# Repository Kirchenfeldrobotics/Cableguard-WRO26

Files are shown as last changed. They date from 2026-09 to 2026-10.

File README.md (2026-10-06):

# Cableguard

**Guarding the lifelines of the Alps.** An autonomous robot that inspects steel wire ropes.

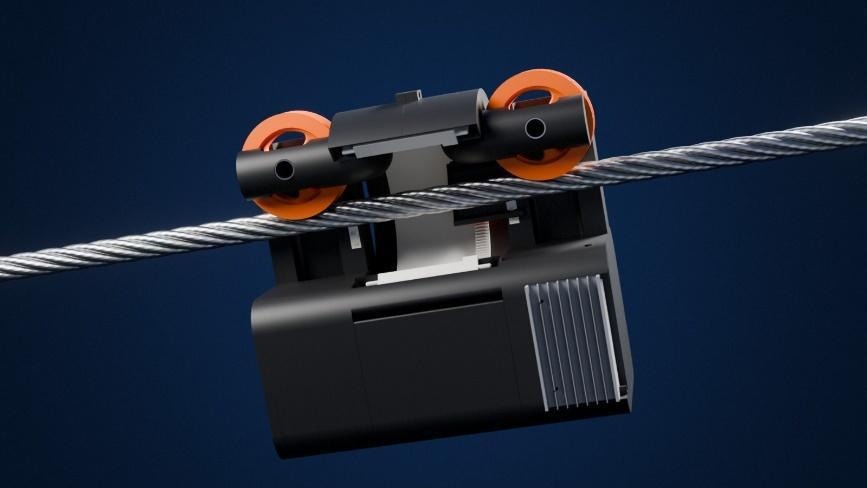
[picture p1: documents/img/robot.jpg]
Cableguard on a rope


**Figure 1.** Cableguard on a rope, rendered from our CAD model.

The operator places Cableguard on the rope and presses start, and the robot works alone. Two
cameras on a rotating ring photograph all four sides of the rope, a YOLO26 network that we
trained on about 22,000 rope images marks eight classes of damage, and the steps of the motor
give the position of every photo. A web app shows the inspection live and compares it with
earlier ones.

We are Kirchenfeldrobotics, a student robotics club from Bern, and we built Cableguard for the
World Robot Olympiad 2026 (Future Innovators, Senior). This README describes how the robot is
built, how its software works and how to run it. The whole story is in our
[project report](documents/CableGuard_Report%20_Kirchenfeldrobotics.pdf), and the
[movie](documents/CableGuard_Movie_Kirchenfeldrobotics.mp4) shows the robot.

## The problem

A steel rope does not fail suddenly. Wires break, corrosion and lightning leave marks, and the
rope weakens over years. On 23 May 2021 the haul rope of the Stresa–Mottarone cable car in
Italy snapped and fourteen people died. Court experts later found that 68 % of the wires at the
break had failed from fatigue and corrosion long before that day.

Switzerland has about 2,450 cableways, and every second small cableway has financial problems.
Today a person checks a rope by riding on a slow-moving gondola, which is slow, expensive and
prone to error. A magnetic test by a testing body happens only every few years. Cableguard
works in the gap between two tests. It photographs the whole rope as often as the operator
wants, and damage that grows slowly shows up as a change between two runs.

Cableguard sees the surface of the rope. It adds to the magnetic test by an accredited body and
never replaces it.

## The robot in numbers

| Property | Value |
| --- | --- |
| Size of the casing | 277 x 160 x 245 mm |
| Weight | 3 kg |
| Test rope | Steel rope, 22 mm diameter, 1.6 m long |
| Scan speed | About 3 cm per second, about 110 m per hour |
| Power | 3S LiPo battery, 11.1 V nominal |
| Computer | Raspberry Pi 5 |
| Motors | 2 x NEMA 23 stepper motor, each with a TB6600 driver |
| Cameras | 2 x Raspberry Pi Camera Module 3 Wide with LED light |
| Network | YOLO26s, 9.5 million parameters, eight classes of damage |
| Parts of one robot | About CHF 400 |

## Mechanics

The body of the robot hangs below the rope. Two wheels on top carry it, and the rope passes
through the upper part of the casing, where a ring with the two cameras surrounds it (Figure 2).

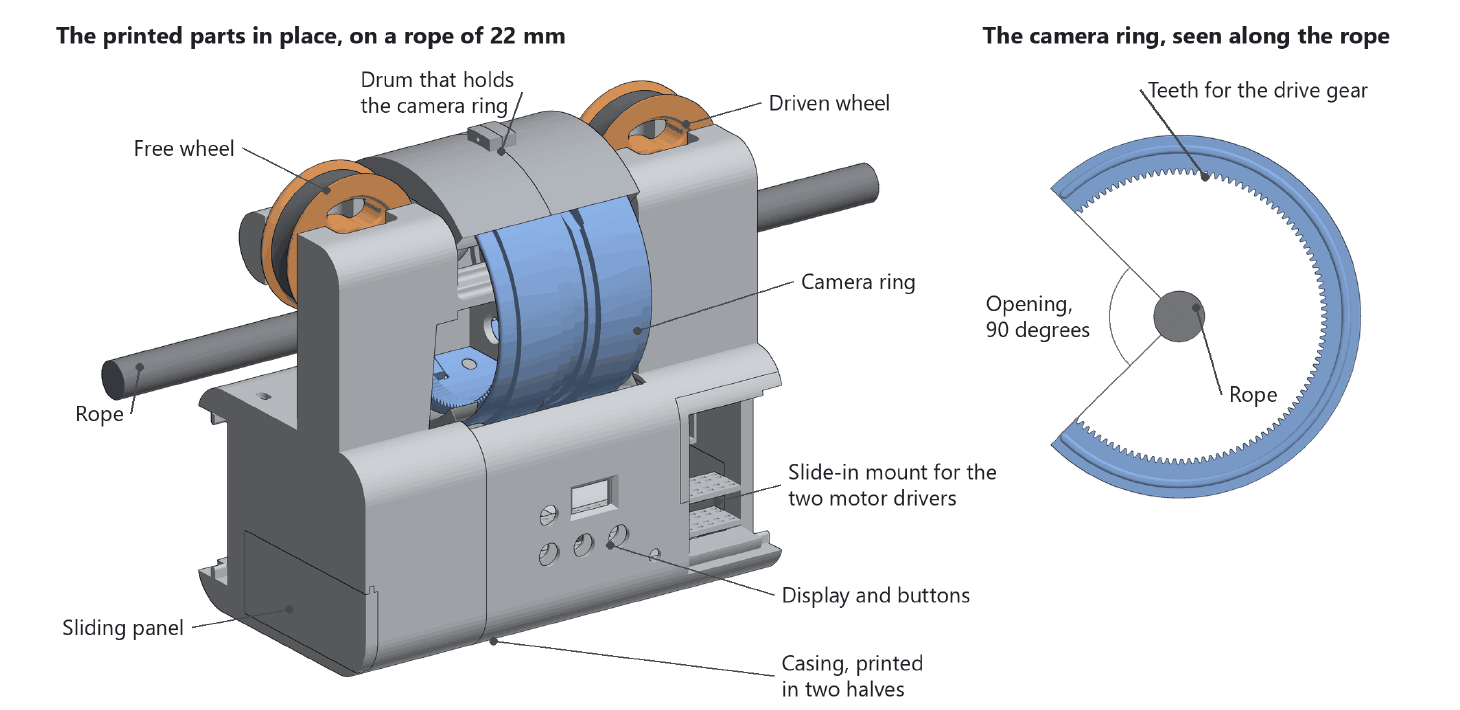
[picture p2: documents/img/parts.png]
The printed parts and the camera ring


**Figure 2.** The printed parts of the robot and the camera ring, drawn from our CAD model.
Motors, belt, cameras and electronics are not shown.

### Drive

The robot rides on two wheels. A NEMA 23 stepper motor drives one of them through a GT2 belt
with a printed tensioner, and the second wheel runs free. The first wheels were printed from PLA
and slipped on the steel. The current wheels have an insert of flexible TPU with a V-shaped
groove. The weight of the robot presses the rope into the V, and this wedge gives the grip that
a flat wheel does not have.

We chose a stepper motor because it moves in fixed steps, 200 per turn, each split into 8
microsteps by the driver. The robot counts every microstep it sends, so it knows its position
without an extra sensor. The weakness of counting steps is slip: if the wheel slips, the robot
believes it is further along the rope than it is. We have not measured slip yet.

### Why a camera ring

A rope is round, and one camera sees less than half of it. The testing institutes therefore
mount four cameras around the rope. We wanted the same coverage with fewer parts. The Raspberry
Pi 5 has two camera connectors, and every further camera adds a cable, weight and a picture for
the network to process. So two cameras sit opposite each other on a ring, and a second NEMA 23
turns the ring through a printed gear.

The ring has an opening of 90 degrees. To put the robot on a rope, the ring turns to its open
position, the rope slips through the opening into the centre of the ring and the wheels come to
rest on the rope. Two rules follow from the hardware. The ring always swings back the way it
came, because the cameras hang on their cables and a ring that kept turning would wind them up.
And since the ring has no end switch, whoever sets up the robot leaves it at its parking angle
and the software counts every step from there.

### Casing and material

Every structural part is 3D printed in PLA: both halves of the casing, the drum that holds the
camera ring, the wheel hubs and all mounts, 16 pieces in total. Only the axles, spacers, screws
and belts are bought parts. We print because we can redesign a part ourselves and test it a day
later, without a workshop.

The casing is a prototype. It encloses the electronics, but it has no seals, and we have not
tested it in rain or frost yet. The files to print are in [`3d-model/print/stl`](3d-model/print/stl),
the CAD files in [`3d-model/cad/step`](3d-model/cad/step) and the list of all parts in
[`3d-model/BOM.md`](3d-model/BOM.md).

## Electronics

One Raspberry Pi 5 runs everything on the robot: both motors, both cameras, the neural network
and the connection to the server.

| Component | Part | Connected to |
| --- | --- | --- |
| Computer | Raspberry Pi 5 | |
| Drive motor | NEMA 23 stepper motor with TB6600 driver | Step GPIO 18 (pin 12), direction GPIO 23 (pin 16) |
| Ring motor | NEMA 23 stepper motor with TB6600 driver | Step GPIO 12 (pin 32), direction GPIO 16 (pin 36) |
| Cameras | 2 x Raspberry Pi Camera Module 3 Wide with LED light | Both camera ports of the Pi |
| Distance sensor | TOF200C (VL53L0X laser sensor) | I2C bus 1, SDA on pin 3, SCL on pin 5 |
| Display | 0.96 inch OLED (SSD1306), 128 x 64 pixels | I2C bus 1, address 0x3C |
| Buttons | Red start button, white stop button. A third button is wired and has no function yet | GPIO 5 (pin 29) and GPIO 6 (pin 31), each switched to ground |
| Buzzer | | GPIO 26 (pin 37) |
| Mobile link | LTE module with SIM card | |
| Power | 3S LiPo battery (11.1 V nominal) and step-down converter | Battery voltage directly to the motor drivers, 5 V from the converter to the Pi |

Three decisions shaped the wiring.

**One computer.** A neural network needs a real processor, and the Pi 5 has the two camera
ports and the GPIO pins we need. A photo, the motor position at that moment and the result of
the network now live in one program, and nothing has to be synchronised over a cable.

**Usable without a phone.** Two buttons, a buzzer and a small display are enough to start a
run, stop it and see what the robot is doing. A button sends the same command as the web app,
so both always do the same thing. Each state has its own sound, and the display shows connection,
position and speed. The Pi pulls both button pins high from the moment it boots, so a button
held down during start-up cannot start the motor.

**Cables that explain themselves.** Three voltage levels, 12 V, 5 V and 3.3 V, meet in a small
space. Every cable carries a three-digit label with two digits for the component and one for
the pin. 013 is pin 3 of the drive motor driver, its step input.
[`documents/cable_label.md`](documents/cable_label.md) lists the labels and
[`documents/pins.md`](documents/pins.md) maps every label to a pin of the Pi.

## Software

The software runs on three devices. The robot inspects on its own, the server stores every
finding and the web app is the window for the operator (Figure 3). We wrote in Python,
TypeScript and C. Everything else we use is open source: FastAPI, Next.js, Ultralytics YOLO,
NCNN and the Raspberry Pi libraries for the cameras and the PIO block.

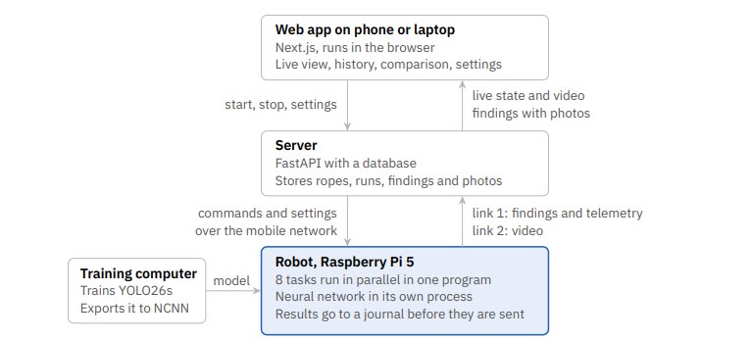
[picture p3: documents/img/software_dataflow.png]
Software architecture: three devices and two links from the robot to the server.


**Figure 3.** Software architecture: three devices and two links from the robot to the server.

### One scan cycle

1. Both cameras take a photo while the ring stands still.
2. The ring swings 90 degrees. During the swing the network analyses the two photos.
3. Both cameras take a second photo of the two sides that were hidden.
4. The ring swings back and the network analyses the second pair.
5. Every result is written to a journal with the position of the robot at the moment of the
   photo.

Only the shutter needs a ring that stands still. The network can work while the cameras move,
so turning and analysing happen at the same time (Figure 4).

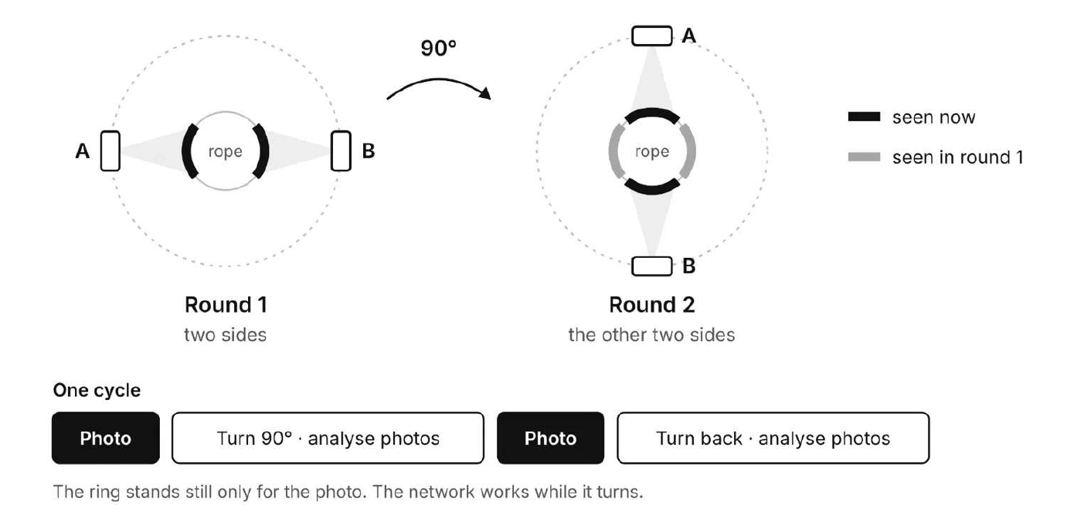
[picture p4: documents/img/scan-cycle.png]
Scan cycle of the camera ring


**Figure 4.** Scan cycle of the camera ring: two rounds of photos and one quarter turn.

Each camera delivers two pictures at once, 640 x 640 pixels for the network and 640 x 480 for
the live view. The scan cycle is one of nine tasks that run in parallel in one program
([`robot/src/app/main.py`](robot/src/app/main.py)).

| Task | What it does |
| --- | --- |
| Control link | Holds the connection for commands and results, sends the journal and a heartbeat every 5 seconds |
| Video link | Sends the newest picture of each camera |
| Frame stream | Takes the small picture of both cameras for the live view |
| Detection | The scan cycle: photos, quarter turns, network, reports |
| Guard | Stops the drive when the connection is lost while driving |
| Telemetry | Reports speed, position and state twice a second |
| Distance | Reads the distance sensor and watches for a rope socket |
| Display | Redraws the display |
| Update | Runs the update script when the operator asks for it |

### The robot sets its own speed

In the first weeks the operator chose the speed in the web app. A robot that drives faster than
its network can analyse leaves stripes of rope that nobody looks at, so now the robot measures
itself. At every start it runs nine test cycles and times the cameras and the network
separately. One photo covers a length *L* of rope, and the robot may travel exactly *L* per
cycle.

| What the robot calculates | Formula |
| --- | --- |
| Time for one quarter turn | `t_turn = max(H · D / R, t_ring)` |
| Time for one cycle | `T = R · (C / R + t_turn)` |
| Driving speed | `v = L / T` |

*C* is the camera time and *D* the network time of one cycle, *R* = 2 the number of photo
rounds and `t_ring` the fastest quarter turn of the ring. *H* = 1.5 is a safety factor, because
the network needs longer for a photo with damage than for the clean rope it was timed on. An
example: with *L* = 60 mm, *C* = 0.14 s and *D* = 1.2 s, which is 0.3 s per photo, the cycle
takes *T* = 1.94 s and the robot drives 31 mm per second, about 110 m per hour. The operator
only chooses start, stop and the direction.

The network sets the pace, and two parts can limit it. If the ring cannot swing a quarter turn
in the time the network needs, it takes the time it needs and the whole cycle grows around it.
And the speed stays inside the limits of the drive: a drive that cannot go slowly enough leaves
a gap between two photos, and the robot writes a warning to its log. The code is in
[`robot/src/vision/pacing.py`](robot/src/vision/pacing.py).

### Knowing the position

A finding is only useful with its position, and the position is the count of motor steps. Every
pulse has to arrive on time, also while the processor is busy with the network. Our first driver
made the pulses in Python, and the motor stuttered whenever the network ran.

The Raspberry Pi 5 contains a hardware block called PIO, four small state machines that run
independently of the processor. We wrote a program of seven instructions for it and a small C
library around it. The software hands the hardware a block of pulses, and the hardware plays it
with a resolution of one microsecond. The robot adds a block to its position only after the
hardware reports it as played, so the count cannot run ahead of the motor.

```
.side_set 1 opt
.wrap_target
    pull block      side 0       ; wait for a block, STEP stays low
    out x, 16                    ; x = steps - 1, OSR keeps the low-time count
step:
    mov y, osr      side 1 [7]   ; STEP high for 10 cycles
    nop                    [1]
low:
    jmp y-- low     side 0       ; STEP low for y + 1 cycles
    jmp x-- step
    push noblock                 ; block done
.wrap
```

The complete program of the PIO block for one stepper motor, from
[`robot/src/motion/stepgen.c`](robot/src/motion/stepgen.c).

Both motors use the same program, one state machine each. A block is one word: the number of
steps and the pause between them. While the robot drives, a thread feeds the hardware blocks of
20 milliseconds and keeps three of them queued. That is enough for a moment in which the
processor is busy, and few enough that a stop command does not wait behind a long queue.

### The neural network

We use YOLO26s, an object detector with 9.5 million parameters that was released in January
2026 for small computers without a graphics card. It draws a box around every damage and gives
a score of how sure it is.

For training we merged two public collections of rope photos with a script that unifies their
class lists. The merged set has about 22,000 images with 37,513 marked damages in eight classes.
We trained for 150 rounds on a graphics card and converted the result to NCNN, a format that
runs fast on the ARM processor of the Pi. On the validation photos, which were not used for
training, the network finds 96 % of all marked damages, and 74 % of its boxes are real damages.

| Class | AP50 | Marked damages in the data | Reported as |
| --- | --- | --- | --- |
| `wear` | 0.95 | 11,547 | Loss of metallic area |
| `kink` | 0.92 | 346 | Local fault |
| `bird_caging` | 0.87 | 488 | Local fault |
| `unknown_defect` | 0.72 | 580 | Local fault |
| `broken_wire` | 0.69 | 10,054 | Local fault |
| `mechanical_damage` | 0.55 | 3,326 | Local fault |
| `thunderbolt` | 0.48 | 4,025 | Local fault |
| `break` | 0.28 | 7,147 | Local fault |

Average precision per damage class at IoU 0.5 on the validation set, first training run on 13
September 2026. The mean is 0.68.

Two decisions follow from these numbers. The robot reports a box as soon as the network is 10 %
sure. A false alarm costs the operator one look at a photo, and a missed broken wire can cost
much more. And it reports each damage in the two groups that rope inspectors know, local fault
(LF) and loss of metallic area (LMA). The table shows why that helps. The network confuses
`break` with `broken_wire` and `thunderbolt` with `mechanical_damage`, because the two photo
collections use different names for the same damage. All four are local faults, so the report of
the robot stays correct.

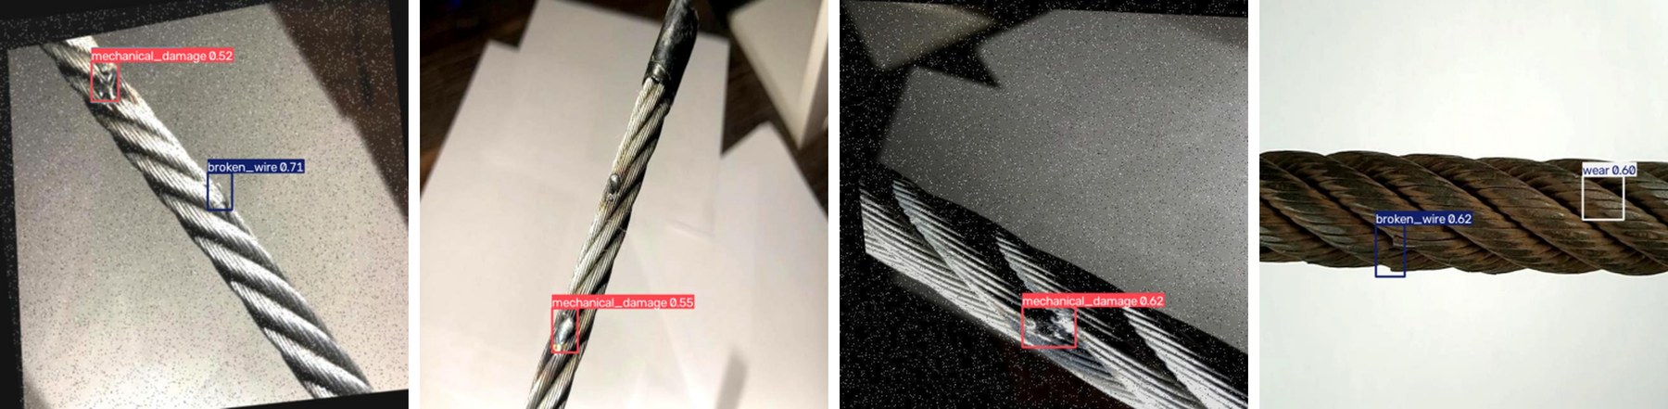
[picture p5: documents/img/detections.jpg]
Detections of our network


**Figure 5.** Four photos from the public test set with the boxes and confidence values of our
network.

The network runs as a separate program. NCNN holds the lock of the Python interpreter for a
whole analysis, so before that change every analysis froze the whole robot for a few hundred
milliseconds, including the thread that feeds the motor
([`robot/src/vision/detector.py`](robot/src/vision/detector.py)).

These numbers come from photos of other people's ropes. On our own test rope the detection
works well in our runs, but we have not yet counted hits and misses on prepared damage.

### Passing a rope socket

A rope ends in a thick metal fitting, the rope socket, and the camera ring cannot turn past it.
A laser distance sensor looks ahead. While the robot still stands it averages ten readings to
learn what the sensor normally sees. When something appears 10 cm nearer than that, the ring
parks at the one angle that leaves room for the socket and the network pauses. 50 cm after the
last sighting the ring closes and the scan continues. A tower is passed the same way.

The sensor compares with its own calibration and not with a fixed distance, because where the
beam lands depends on how the sensor sits and which rope it is. Two things can open the robot.
An opening by the sensor ends once the robot has driven clear. An opening the operator asked
for in the web app ends only when the operator closes it.

### Two links to the server

The robot keeps two connections to the server, one for commands and results and one for video,
so a video frame cannot delay a stop command. Both are WebSockets, and the robot signs in with
a token.

Every result is written to a journal on the memory card before it is sent, and after a
connection loss the robot continues at the byte where it stopped. If the connection breaks
while the robot drives, it stops and sounds the fault signal, because nobody could stop it
remotely.

Robot and server read their messages from the same file,
[`shared/comm_protocols/messages.py`](shared/comm_protocols/messages.py), so both sides always
speak the same protocol.

| Message | Direction | What it carries |
| --- | --- | --- |
| `alive` | Robot to server | Heartbeat every 5 seconds |
| `motion_telemetry` | Robot to server | Speed and position in microsteps and in metres, the scan speed the robot chose, whether it is open, the versions of the settings and of the software it runs on |
| `distance_telemetry` | Robot to server | Reading of the distance sensor |
| `vision_telemetry` | Robot to server | One per photo: boxes, class and confidence, position, and the photo itself if something was found |
| `defect` | Robot to server | A finding from a second sensor, kept for the magnetic head |
| `start`, `stop` | Server to robot | Drive in a direction, stop |
| `reset_origin` | Server to robot | Count the position from here, sent when a run is selected |
| `open`, `close`, `socket_watch` | Server to robot | Open or close the ring, arm the distance sensor |
| `settings` | Server to robot | The whole set of settings with a version number |
| `update` | Server to robot | Run the update script |

Telemetry is sent live, because a reading is worth nothing a second later. Photos with findings
go through the journal, because a detection that is not stored is a damage lost. Neither side
confirms a command. The robot reports its state in the telemetry, and the web app shows a
command as carried out only when the telemetry says so.

### Server and web app

The server is a FastAPI program with a database, SQLite by default. It stores ropes, runs,
findings and the photo every finding was made in. A finding belongs to a run, so the server
drops findings while no run is selected. When the operator selects a run, the server tells the
robot to count its position from zero.

The web app shows both camera streams, position and speed live, keeps every inspection of a
rope and compares two of them. One damage is usually photographed several times, so the web app
groups detections of the same type that are less than 0.5 m apart into one finding. In a
comparison, findings less than 1.5 m apart count as the same damage, so the operator sees what
is new and what has disappeared. Every run can be exported as a PDF. Operators log in with a
password or by holding their phone to an NFC tag on the robot.

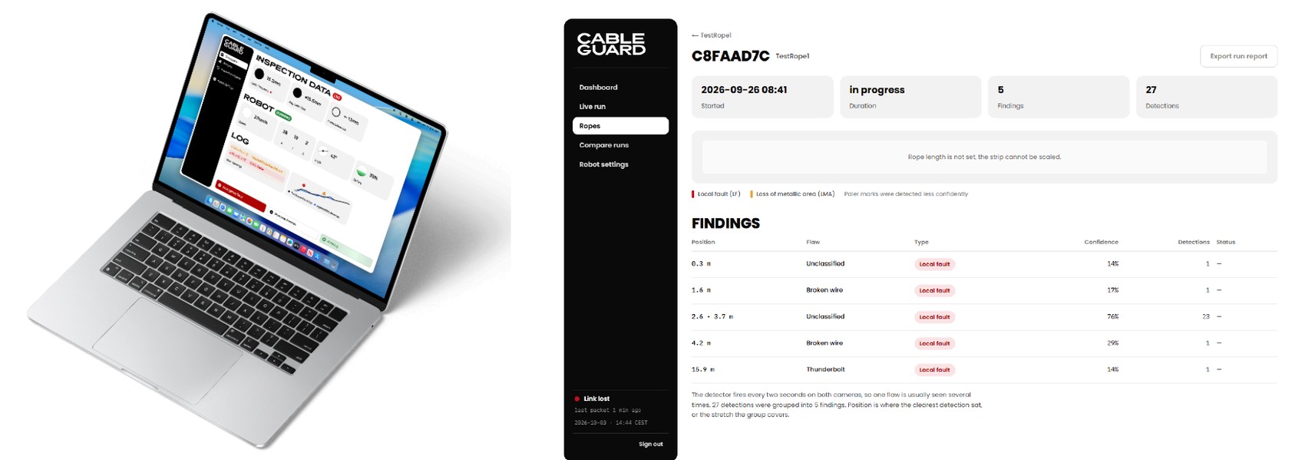
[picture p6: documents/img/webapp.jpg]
The web app


**Figure 6.** The web app: the dashboard on a laptop and the findings of one run with position,
flaw and confidence.

**Settings.** The robot has 31 settings in seven groups, from the microstepping of the drive to
the exposure of the cameras. They are defined once, in
[`shared/comm_protocols/settings.py`](shared/comm_protocols/settings.py), with their limits and
their explanation. The server stores the values of the operator, and the settings page draws
itself from that list, so a new setting is added in one place. The robot boots on its own
defaults and runs without a server.

**Update.** The settings page can also update the robot. The robot then runs the update script
that sits beside the repository on the Pi, which pulls the latest software and restarts the
program. The page shows the commit the robot runs on, so the operator sees that the update
worked ([`robot/src/app/update.py`](robot/src/app/update.py)).

The web app has its own [README](webapp/README.md) with every route and endpoint, and
[DESIGN.md](webapp/DESIGN.md) describes its design.

### What the robot decides by itself

| Decision | What it is based on |
| --- | --- |
| Driving speed | Its own timing test at start-up |
| Speed of the ring | The time the network needs for one pair of photos |
| Open and close for a rope socket or a tower | Distance sensor compared with its own calibration |
| Pause the network | Standing still, which keeps the processor cool |
| Stop | Connection lost while driving |
| Accept new settings | Only when the drive stands and the ring is parked |

## Repository

| Folder | Content |
| --- | --- |
| [`robot/`](robot) | The program on the Raspberry Pi: main program in `app/`, stepper drivers and PIO program in `motion/`, cameras in `camera/`, network and speed in `vision/`, distance sensor in `tof/`, display in `display/`, the two links in `link/` |
| [`backend/`](backend) | The server: routes, database and the hub that passes messages between robot and web app |
| [`webapp/`](webapp) | The web app |
| [`shared/`](shared) | Messages and settings, used by robot and server |
| [`wirerope-training/`](wirerope-training) | Merges the photo collections, trains the network and exports it for the robot |
| [`scripts/`](scripts) | `deploy-model.sh` copies the exported network to the Pi |
| [`3d-model/`](3d-model) | Files to print, CAD files and the list of parts |
| [`documents/`](documents) | Project report, movie, pin and cable legends |

## Getting started

### Server

```bash
cd backend
pip install -r requirements.txt
export CABLEGUARD_ROBOT_TOKEN=<a long random string>
uvicorn app.main:app --port 8021
```

| Variable | What it is for |
| --- | --- |
| `CABLEGUARD_ROBOT_TOKEN` | The token the robot signs in with. Required, and it has to be set in the environment |
| `DEFAULT_USERNAME`, `DEFAULT_PASSWORD` | The operator account, created at the first start |
| `JWT_SECRET` | Signs the logins. Without it every restart logs the operator out |
| `CORS_ORIGINS` | Address of the web app, if it is not served from the same address as the server |
| `DATABASE_URL` | Where the database is. By default a SQLite file in `backend/data/` |
| `NFC_LOGIN_KEY` | The key on the NFC tag. Empty switches the NFC login off |

All but the first can also stand in `backend/.env`. Be careful with data you want to keep: when
`SCHEMA_VERSION` in [`backend/app/database.py`](backend/app/database.py) changes, the server
drops the database and builds it again.

### Web app

```bash
cd webapp
npm install
cp .env.example .env.local    # NEXT_PUBLIC_API_URL points at the server
npm run dev                   # http://localhost:3000
```

### Robot

The robot needs a Raspberry Pi 5 with Raspberry Pi OS, both cameras connected and I2C switched
on. The cameras use `picamera2`, which is a system package of Raspberry Pi OS
(`python3-picamera2`) and therefore not in `requirements.txt`.

```bash
cd robot
pip install -r requirements.txt

# the C library for the PIO block, needs libpio-dev
cd src/motion
gcc -O2 -shared -fPIC -I/usr/include/piolib -o libstepgen.so stepgen.c -lpio -pthread
```

The network is not in the repository, because the code travels over git and the model over
ssh. Export it on the training computer and copy it to the Pi:

```bash
cd wirerope-training
python export_for_robot.py --weights weights/best.pt    # writes robot/models/best_ncnn_model
cd ..
./scripts/deploy-model.sh pi@cableguard.local
```

Then start the program:

```bash
export CABLEGUARD_WS_URL=wss://<server>/api/ws/robot
export CABLEGUARD_VID_WS_URL=wss://<server>/api/ws/video/robot
export CABLEGUARD_ROBOT_TOKEN=<the same token as on the server>

cd robot/src
python -m app.main
```

The robot loads the network, runs its test cycles and sounds two short rising tones when it is
ready. A run on our test rig then looks like this. We turn the camera ring to its open
position, hang the robot on the rope, select a run in the web app and press the red button. The
robot starts to drive, the ring swings back and forth, and both camera pictures appear live in
the web app together with the position. The white button stops the run.

On our robot the program runs as a systemd service, and the update script beside the repository
pulls the software and restarts it.

### Training the network

[`wirerope-training/tutorial-how-to-use.md`](wirerope-training/tutorial-how-to-use.md) describes
every step: download the two photo collections, merge them with `prepare_wirerope.py`, train in
the notebook and export with `export_for_robot.py`. The detector can be tested alone on a
laptop with a webcam:

```bash
python robot/src/vision/detector.py cam
```

### Testing the links

Two scripts test the connection to the server, one from the side of the robot and one from the
side of the browser. Both take `local` or `remote`, and the first needs
`CABLEGUARD_ROBOT_TOKEN`.

```bash
cd backend
python tests/robot_websocket_test.py local
python tests/ui_websocket_test.py local
```

## Challenges and tests

Six problems shaped the current design.

| Problem | What we saw | What we changed |
| --- | --- | --- |
| Wheels slip | Printed PLA wheels slipped on the steel rope | TPU insert with a V-shaped groove that the rope is pressed into |
| Motor stutters | Pulses from Python came late whenever the network ran | Pulses from the PIO hardware block |
| Network freezes the robot | Every analysis blocked all other threads | Network in its own process |
| Rope is skipped | The operator could drive faster than the network could analyse | The robot sets its own speed |
| Photos unusable | Automatic exposure changed the brightness, the focus was wrong | Fixed exposure, gain and white balance, focus locked at 5 cm |
| Position jumps | New drive settings during a ramp changed the meaning of counted steps | Settings apply only while the robot stands |

We test on our own rig, a steel rope of 22 mm diameter and 1.6 m length. There we run complete
inspections: start by button, scan with the swinging ring, findings in the web app, stop.

What is still missing are measurements. We have not yet measured the position error over
distance, the hits and misses on prepared damage, the battery runtime, the steepest slope the
robot can climb or the behaviour in rain and frost, and we have no automated software tests.

Two estimates we will check first. Our test rope is level, but many small cableways are steep.
On a slope of 30 degrees the driven wheel has to pull about 15 N, while only about half of the
weight presses it onto the rope. The battery is the second question. The Pi 5 needs about 7 W
while the network runs, and two NEMA 23 motors on TB6600 drivers can need 10 to 20 W each, also
while they hold still. With 30 to 45 W, a 3S battery of 5,000 mAh would last only one to two
hours.

## Next steps

The prototype works on our test rig. Five steps separate it from a robot that an operator can
use.

1. **Real numbers and better eyes.** We count hits, misses and false alarms on a rope with
   prepared damage. Then we merge the twin classes of the two photo collections and retrain the
   network with photos from our own cameras.
2. **More speed.** At about 110 m per hour a long rope takes more than one night. The network
   sets the speed, so we will test a smaller network, an AI accelerator for the Raspberry Pi and
   a longer photo.
3. **Ready for weather.** A casing of ASA or aluminium with sealed openings, tested in rain and
   frost, and a catch that holds the robot if a wheel leaves the rope.
4. **Inside the rope.** We have a ring of eight Hall sensors from an earlier version, and the
   software already has a message for a second sensor. Missing are the magnets in a yoke
   machined from iron, a safe way to put this head on the rope and a field model that turns the
   readings into findings.
5. **A report an inspector can file.** The web app already exports a run as a PDF with every
   finding, its photo and its position. Missing are a rating of the severity and a clear
   statement of what was not inspected.

## Team

| Member | Responsibility | In this project |
| --- | --- | --- |
| Jakob Gutersohn | Hardware | Designed every custom part in CAD, assembled the robot and soldered |
| Nils Buchli | Software and electronics | Robot software on the Raspberry Pi and the server. Set up and tested the electronics with Valéry |
| Valéry Piot | Software and electronics | Web app, login, the network with its training and parts of the Raspberry Pi. Wired all components and set up and tested the electronics with Nils |
| David Bänziger | Coach | Helped us plan and organise and reviewed our work |

We are in the third year of Gymnasium Kirchenfeld in Bern, and Kirchenfeldrobotics is a
registered association ([kirchenfeldrobotics.ch](https://kirchenfeldrobotics.ch)).

We want Cableguard to outlive this competition: a robot on every historic ropeway, and every
broken wire found on the day it breaks, not on the day the rope fails.

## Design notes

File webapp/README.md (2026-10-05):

# CableGuard webapp

Operator console for the CableGuard rope inspection robot. Next.js 16 (App Router),
React 19, Tailwind CSS 4, TypeScript. It talks only to the FastAPI backend in
`../backend`, never to the robot directly.

The visual language is documented in [DESIGN.md](./DESIGN.md).

## Getting started

```bash
npm install
cp .env.example .env.local   # point NEXT_PUBLIC_API_URL at your backend
npm run dev                   # http://localhost:3000
```

For local development the backend must allow the webapp origin, for example
`CORS_ORIGINS=http://localhost:3000` in `backend/.env`.

| Script | Purpose |
| --- | --- |
| `npm run dev` | Development server |
| `npm run build` / `npm start` | Production build and server |
| `npm run lint` | ESLint (Next.js core web vitals and TypeScript rules) |
| `npm run typecheck` | Generate route types and run `tsc` |

### Environment

| Variable | Default | Description |
| --- | --- | --- |
| `NEXT_PUBLIC_API_URL` | empty (same origin) | Backend base URL for REST and WebSockets. Inlined at build time. |

## Structure

```
app/                      Routes only: thin server components, metadata, error and not-found
  page.tsx                Dashboard
  live/                   Live run
  ropes/                  Ropes list
    [ropeId]/             Rope detail
      runs/[runId]/       Run detail
        defects/[defectId]/  Defect detail
  compare/                Compare two runs (?rope=&a=&b=)
  settings/               Robot settings
features/<screen>/        One client view per screen: data loading and composition
components/
  ui/                     Design system primitives (see DESIGN.md)
  layout/                 App shell (sidebar)
  rope/ camera/ inspection/  Domain components
lib/
  api/                    Backend contract types and typed REST client
  robot/                  WebSocket connections (robot link, video)
  hooks/                  useApi, useRopeHistory, useCurrentSelection, useNow
  defects.ts format.ts routes.ts config.ts cn.ts
public/                   Logo
```

Conventions:

- Pages in `app/` stay thin: read `params` or `searchParams`, render a view from `features/`.
- All URLs come from `lib/routes.ts`, all endpoints from `lib/api/client.ts`.
- When the backend changes, update `lib/api/types.ts` first. It mirrors
  `backend/app/schemas.py` and `shared/comm_protocols/messages.py`.

## Data flow

| Channel | Endpoint | Used for |
| --- | --- | --- |
| REST | `POST /api/auth/login`, `POST /api/auth/nfc`, `GET /api/auth/me` | Sign in with a password or the robot's NFC tag, restore a session |
| REST | `GET /api/ropes`, `POST /api/ropes`, `PATCH /api/ropes/{id}`, `DELETE /api/ropes/{id}` | Ropes list, add (name and length), correct the length, remove |
| REST | `GET /api/runs?rope_id=`, `POST /api/runs`, `POST /api/runs/{id}/finish`, `DELETE /api/runs/{id}` | Run history per rope, start, finish, remove |
| REST | `GET /api/defects?run_id=`, `GET /api/defects/{id}/frame` | Defects per run (live view polls every 5 s), the frame a defect was found in |
| REST | `POST /api/defects/review`, `POST /api/defects/remove` | Mark the detections of a finding reviewed, delete a false positive |
| REST | `GET /api/current`, `POST /api/current` | Rope and run selected on the server |
| REST | `GET /api/settings`, `PUT /api/settings`, `POST /api/settings/reset` | Robot settings |
| WebSocket | `/api/ws/ui` | `robot_status`, `alive`, `motion_telemetry`, `distance_telemetry`, `vision_telemetry`, `current_changed`, `settings_changed`, `error`; sends `start`, `stop`, `open`, `close` and `socket_watch` |
| WebSocket | `/api/ws/video/ui` | JPEG frames of two cameras, first byte is the camera index |

`RobotLinkProvider` (in the root layout) keeps one UI socket open for the whole app and
reconnects with backoff. The robot counts as connected only while the server reports it
online and it has been heard from (heartbeat or telemetry) in the last 12 s, because the
server itself only notices a dead robot link when its pings time out. Telemetry older than
2 s is not shown as current.

The video socket is only opened while the live view is mounted. A camera tile that receives
no frame for 2 s dims its last image and marks it as not live.

Neither the server nor the robot acknowledges commands. The live view therefore treats a
command as carried out only once telemetry reports the expected motion, and warns the operator
if that has not happened 5 s after sending.

## Feature status

Everything on screen is backed by the robot or the backend:

- Robot link state, last packet and telemetry age, position on the rope, drive speed, detector rate
- Drive control: start in a direction and stop; rope socket: open, close, arm the distance sensor
- Camera A and B live streams
- Ropes list with add (name and length) and remove, rope detail with length correction, run history with remove, finding trend
- Rope strip drawn to scale: scrolls sideways on a long rope, with an overview of the whole rope
- Run detail, defect detail with the stored camera frame, the detector's box and the change since the previous run
- Review: a finding is marked reviewed or unreviewed, a false positive is deleted for good
- Run report as a PDF, built in the browser (`features/run/run-report.ts`, jsPDF loaded on the click)
- Run comparison (findings within 1.5 m count as the same finding)
- Robot settings, read from and written to the backend

Defects have no severity: findings are coloured by their type instead, see DESIGN.md.

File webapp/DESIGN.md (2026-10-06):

# CableGuard design system

The webapp implements the Claude Design project **CableGuard v2** (`CableGuard v2.dc.html`,
with the rope strip from `RopeStripBold.dc.html`). This file is the reference for anyone
adding screens: use these tokens and components rather than new one-off styles.

## Principles

- **Operator first.** Large numbers, short labels, one status colour per meaning. The
  screen is read on site, often in a hurry.
- **Black, white, one red.** Colour is reserved for status. Everything else is ink on
  white or light grey.
- **Never invent data.** If the robot or backend does not provide a value, show `—`
  (`NOT_AVAILABLE` in `lib/format.ts`). Controls for features that do not exist yet are
  rendered **disabled**, never wired to fake state. The webapp keeps no copy of the robot's
  constants: anything it names is read from `GET /api/settings` (`useRobotSettings`).
- **Say it once, in a few words.** No text explains how a feature works, and no text repeats
  what a badge, a card, a button label or the sidebar already shows. What is left is a note
  of a few words. A `title` tooltip is only for a disabled button whose reason is not on the
  screen (`Stop first`) and for data (the label on a rope mark). The
  settings page is the exception: its explanations come from the server with each setting.

## Tokens

All tokens live in `app/globals.css` (`@theme`) and are used as Tailwind classes, for
example `bg-surface`, `text-text-muted` or `rounded-card`. Do not write hex values in
components.

### Colour

| Token | Hex | Use |
| --- | --- | --- |
| `ink` | `#0A0A0A` | Text, sidebar, primary buttons |
| `ink-soft` | `#2C2C2C` | Sidebar dividers, primary hover |
| `text-muted` | `#4A4A4A` | Secondary text, card labels |
| `text-subtle` | `#6E6E6E` | Table headers, notes, back links |
| `text-faint` | `#8C8C8C` | Sidebar meta, disabled text |
| `text-inverse-muted` | `#D8D8D8` | Inactive nav items on ink |
| `canvas` | `#FFFFFF` | Page background |
| `surface` | `#F2F2F2` | Cards and panels |
| `surface-hover` | `#F7F7F7` | Table row hover |
| `surface-strong` | `#E4E4E4` | Rows inside panels, muted indicators |
| `neutral-soft` | `#E8E8E8` | Neutral pill, disabled primary |
| `line` / `line-strong` | `#EDEDED` / `#E2E2E2` | Table rules |
| `border` | `#DADADA` | Inputs and secondary buttons |
| `mark-muted` / `mark-tick` | `#BFBFBF` / `#D6D6D6` | Unchanged marks, older trend bars |
| `danger` | `#C11119` | Broken wire (LF), Live and Link lost badges |
| `danger-strong` / `danger-deep` | `#A50C13` / `#7F080E` | Red text, `danger` buttons |
| `danger-soft` | `#FBE3E5` | Alert banner, red rows |
| `warning` / `warning-ink` / `warning-soft` | `#E8A33D` / `#8A5A00` / `#FDF0DC` | Corrosion (LMA) |
| `success` / `success-ink` / `success-soft` / `success-line` | `#1E9E4A` / `#14713A` / `#E9F8EE` / `#C3E7CF` | Connected, running |
| `video` / `video-stripe` / `video-text` | `#1A1D1F` / `#212528` / `#C9CDCF` | Camera tiles |

Defects have no severity in the backend yet, so the design's "Action required" red and
"Monitor" amber are mapped to the two buckets the robot sorts its detector classes into
(`kindTone` in `lib/defects.ts`): local faults are red, loss of metallic area amber. The
model knows eight classes and seven of them are local faults, so colour alone is coarse:
the class itself is always shown as text next to it (`defectClassLabel` in `lib/format.ts`).

### Typography

Poppins for UI text, IBM Plex Mono for measurements, ids and timestamps. Both are loaded
with `next/font` in `app/layout.tsx` and exposed as `font-sans` and `font-mono`.

| Role | Style |
| --- | --- |
| Page and section title | 30px / 800, uppercase, `-0.01em` tracking (24px on phones) |
| Sub-title inside a column | 18px / 800, uppercase |
| Card value (stat, fact, comparison) | 22px / 700 (18px on phones) |
| Large button, input on a phone | 16px |
| Body, buttons, inputs | 14px / 400–600 |
| Labels, links, table cells | 13px |
| Status badge, table header, notes | 12px |
| Scale labels, captions in mono | 11px |

These eight sizes (11, 12, 13, 14, 16, 18, 22 and the title) are the whole scale. A size in
between is a sign that a screen is styling something a component already styles.

Mono is for measurements, ids and timestamps. A word stays in the text font even when it
sits in a column of numbers: `FactList` rows are mono only where `mono` is set.

### Shape and spacing

| Token | Value | Use |
| --- | --- | --- |
| `rounded-shell` | 18px | Sidebar |
| `rounded-card` | 14px | Cards, panels, camera tiles |
| `rounded-control` | 10px | Buttons, inputs, nav items |
| `rounded-row` | 9px | Log rows |
| `rounded-full` | | Badges and indicators |

### Sizes and rhythm

| Token | Value | Use |
| --- | --- | --- |
| `control` | 44px | Height of every button, input and dropdown (`h-control`) |
| `control-lg` | 58px | The main action of a screen: start and finish a run, open the robot, sign in |
| `section` | 38px | Above a section heading (`mt-section`) |
| `stack` | 18px | Under a heading, and between two blocks that follow each other (`mt-stack`, `gap-stack`) |

Cards sit 14px apart, the app has 12px of outer padding. A control never gets its own
padding or height on a screen: if `md` and `lg` do not fit, the screen is asking for the
wrong control.

A spacing token also becomes a size utility under other prefixes, so its name must not be a
CSS display value: a token called `block` turns every `inline-block` into an 18px wide box.

`Panel` has two paddings and no third: `content` (16px, 22px from `sm`) for a strip,
controls, a chart or a form, and `list` for rows that bring their own vertical padding
(settings, fact lists).

## Layout

- `app/layout.tsx`: 236px sticky black sidebar on the left and main content up to 1280px
  wide.
- A page is titled like its navigation entry. The page header row is as tall as a control
  whether or not it holds a button, so the title sits at the same height on every page,
  and the scrollbar keeps its room on a page too short to need one, so nothing shifts
  sideways between pages.
- The sidebar footer always shows the robot link (green or red dot), the time since the
  last packet and the local clock.
- **Phones and tablets** (below `lg`): the sidebar is replaced by a sticky black top bar
  (logo, robot link with the time since the last packet, sign out) and a fixed bottom tab
  bar with the same destinations under short labels (Status, Live, Ropes, Compare, Robot).
  The tab bar follows the sidebar's rules: Live only appears while a run is recording, and
  carries a red dot then. Both bars pad themselves with the safe-area insets
  (`viewportFit: "cover"`), and `--tabbar-h` is the tab bar's height for anything that
  has to sit above it.

### Phone rules

- Below `sm`, headings drop to 24px, stat and fact cards go two to a row with a 20px
  status circle, and main action buttons fill the row. The actions of a page header get a
  row of their own under the title, starting at the left edge like everything else.
- Tables become one card per row (`.stack-table` in `globals.css`). Give every `Td` a
  `label` (its column header), mark the identifying cell `phone="primary"` and a row
  action `phone="end"`. A cell that is empty, such as a row action that is not offered,
  takes no room on the card.
- Inputs use 16px text below `sm`, otherwise iOS zooms the page when they are focused.
- The live screen puts what is being tracked first (numbers, position on rope, cameras,
  then drive, rope socket and log), the cameras swipe sideways, and the motion state with Stop is
  pinned above the tab bar. That pinned Stop replaces the one in the drive panel, so
  there is never more than one Stop on screen.

## Components

| Component | File | Notes |
| --- | --- | --- |
| `PageHeader`, `SectionTitle`, `SubTitle`, `HeadingMeta` | `components/ui/heading.tsx` | Title rows. Meta text, actions and a note are props of the row, never siblings of the heading: the row owns the spacing |
| `Button`, `ButtonLink`, `TextLink`, `RingIcon` | `components/ui/button.tsx` | `primary`, `secondary`, `danger`; `md` (44px) or `lg` (58px). `TextLink` is the small action next to a heading |
| `Input`, `Field` | `components/ui/input.tsx` | The one text field, and a control under its caption |
| `Dropdown` | `components/ui/dropdown.tsx` | Listbox in the control shape; a native `<select>` cannot be styled to the tokens |
| `Pill` | `components/ui/pill.tsx` | `status` variant for headers, `tag` inside tables |
| `StatCard`, `FactCard`, `Panel`, `CardGrid` | `components/ui/card.tsx` | Stat cards carry a 46px status circle. Labels sit on the bottom edge, so they stay in line when a value wraps |
| `Table`, `Th`, `Td`, `LinkRow` | `components/ui/table.tsx` | Rows navigate on click and Enter |
| `RemoveButton` | `components/ui/remove-button.tsx` | Two-step remove at the end of a table row (ropes, runs) |
| `LogRow`, `InfoRow` | `components/ui/log-row.tsx` | Tinted rows for detections and changes |
| `FactList` | `components/ui/fact-list.tsx` | Label and value rows on a panel |
| `Notice`, `StatusMessage`, `BackLink` | `components/ui/feedback.tsx` | Alerts, loading, empty and error states |
| `RopeStrip`, `RopeStripSync`, `findingMarks`, `DefectLegend` | `components/rope/` | Unrolled rope with metre scale and finding marks, drawn to scale and scrolling sideways when the rope is longer than the screen |
| `RopeLengthInput` | `components/rope/rope-length-input.tsx` | Length in metres with its unit, for adding a rope and correcting its length |
| `CameraFeed` | `components/camera/camera-feed.tsx` | Live JPEG stream, dimmed with a "Not live" badge when frames stop, or striped placeholder |
| `DetectionFrame` | `components/camera/detection-frame.tsx` | The stored JPEG a defect was found in, with its box on top; fetched as a blob because an `<img>` cannot send the token |
| `RunStatePill` | `components/inspection/run-state-pill.tsx` | Link lost, Live or Idle |
| `Sidebar` | `components/layout/sidebar.tsx` | Desktop navigation and link status |
| `MobileTopBar`, `TabBar` | `components/layout/mobile-nav.tsx` | Phone navigation and link status |
| `useNavItems` | `components/layout/nav.tsx` | Destinations and icons shared by both |

## Patterns

- **Status circle meanings** (`StatCard` `indicator`): `success` connected, `danger`
  link lost, `alert` needs review, `warning` detections, `ring` current selection
  (rope, position), `solid` motion, `muted` neutral or unavailable.
- **Review**: the operator reviews findings, not detections. `Mark reviewed` on the defect
  page sets every detection of the finding in one request, and a finding counts as reviewed
  only while all of them are, so a detection that joins it later in a live run opens it
  again. `Flag false positive` deletes the detections for good after a second click
  (`Confirm delete`): there is no false-positive state to show, count or undo. Unreviewed
  findings are counted per run on the rope page and over all runs of the selected rope on
  the dashboard, where the `alert` circle shows while any are left.
- **Run report**: `Export run report` builds a PDF in the browser
  (`features/run/run-report.ts`): the run's numbers, the rope with its findings, the
  findings table with their review status, and one photo per finding with the detector's
  box. jsPDF is loaded on the click, it is far heavier than the page. A PDF cannot read the
  stylesheet, so the report module carries its own copy of the few colour tokens it uses,
  and the PDF's built-in Helvetica stands in for Poppins.
- **Findings, not detections**: the robot stores one row per detection and runs the
  detector every two seconds on both cameras, so one flaw arrives as several rows a few
  centimetres apart. `clusterDefects` groups rows of the same kind that are closer than
  `CLUSTER_GAP_M` into a **finding**, and every screen counts and draws findings.
  Detections stay reachable: the run page shows how many back each finding, and the defect
  page lists them. Comparing runs also works on findings, otherwise repeat sightings would
  be counted as new defects.
- **Tables**: columns are 24px apart, so a right-aligned number never touches the column
  after it. A status in a table is plain text: what is still to do in the strong weight,
  what is done muted.
- **Error text** is the server's own sentence and nothing else (`ApiError` in
  `lib/api/client.ts`): no endpoint, no status code.
- **Rope strip**: the rope is a white bar on the grey panel, with red marks for local
  faults and amber ones for loss of metallic area. A finding is
  drawn over the stretch its detections cover, down to a minimum width so a single one
  stays clickable, and faded by its confidence so a weak detection does not read like a
  certain one. In comparisons, marks also found in the reference run are thin and grey,
  new ones are wider and keep full opacity. The black vertical line is the robot position
  (only drawn when a position is known).
- **Rope strip scale**: the strip is drawn at 10 px per metre (`PX_PER_M` in
  `components/rope/strip-layout.ts`), about 100 m across a desktop panel and 30 m on a phone.
  A rope that fits is stretched to the full width. A longer one scrolls sideways and gets an
  overview bar underneath: the whole rope in one line, a tick per mark and a frame around the
  part on screen. The overview is the strip's scrollbar (drag, click, arrow keys, Page
  Up/Down, Home, End), the browser's own is hidden. The scale is what keeps marks apart:
  findings of one type are never closer than `CLUSTER_GAP_M`, which is wider than a mark at
  10 px per metre. A local fault and a loss of metallic area on the same spot share the bar
  height, the fault on top. A mark's click margin stops halfway to its neighbour. The scale
  labels step by 1, 2, 5, 10, ... metres, whatever keeps them about 64 px apart.
- **Rope strip position**: a strip opens at the start of the rope. On the live screen it
  follows the robot and moves on when the robot nears the edge. While the operator has hold
  of the strip it stays where they put it, and it follows again once they have let go with
  the robot on screen. Strips inside one `RopeStripSync` scroll together (run comparison).
- **Rope length** is asked for when a rope is added and can be corrected on the rope page
  (`Edit length`). Only a rope from before the length was asked for has none, and its strip
  says so instead of drawing.
- **States**: every data view handles loading (`Loading…`), error (red text) and empty
  (a few words saying what is missing). An empty list whose count already shows as 0 on a
  card is not drawn at all, heading included.
- **Destructive actions** need a second click (`Remove` becomes `Confirm remove`,
  `Flag false positive` becomes `Confirm delete`).
- **Stop** is never disabled while the server socket is open, even if the robot is reported
  offline. The server answers with an error if it cannot forward it. There is no separate
  emergency stop: it sent the same command as Stop, and a second button that looks more
  urgent than the one that does the job is worse than no button.
- **Drive controls**: the operator only starts, stops and picks the direction. The robot
  times its own detector at startup and drives exactly fast enough for the camera frames to
  cover the rope end to end (`robot/src/vision/pacing.py`), and reports the speed and
  detector rate it settled on in every motion telemetry packet. Start is disabled while the
  robot is unreachable or already scanning, and the direction buttons are disabled while it
  moves, so no single click can reverse a moving machine. A command is reported as carried
  out only when telemetry shows it, never because the socket accepted it.
- **Rope socket**: the camera ring cannot turn past the fitting a rope ends in, so the robot
  *opens* — the ring parks clear of it and the detector stops, while the drive and the camera
  streams carry on. The live view has the large Open/Close button and, beside it, the small
  switch for the robot's own trigger on the distance sensor; both read their state from
  `robot_open` and `socket_watch` in the motion telemetry, never from what was clicked. An
  opening the operator asked for ends only on their click, one the sensor made closes itself
  once the robot has driven clear. The opening threshold itself is set on the settings page.
  The sensor triggers on a *departure* from what it read at startup, not on a distance, so
  the panel also shows the reading it calibrated on: `Not calibrated` there means it found
  nothing to measure against, which is why the robot will not open by itself. Arming the
  sensor is not a setting: it is a command like Start and Stop, and lives only in the live
  view.
- **Settings** are the robot's own constants (`shared/comm_protocols/settings.py`), kept in
  the backend's database and sent to the robot as a `SettingsCmd`. The page draws itself from
  what `GET /api/settings` returns: the label, the explanation, the unit and the bounds of
  every setting come from the server, so no setting is ever described twice. A change is a
  `PUT` of only the settings that moved, and the server refuses one while the robot reports
  movement, so the page disables its inputs then. The robot echoes the version it is running
  on in every motion telemetry packet, and the page says a change is **in force** only when
  that version matches the stored one, never because the `PUT` came back 200.
- **Robot update**: `Update` in the first box of the settings page has the robot run its own
  update script (`POST /api/robot/update`, `robot/src/app/update.py`), after a second click.
  The server refuses it for a robot that is offline or moving, and the action is disabled
  then. The row reads the robot's telemetry and never the click: `software` is the commit
  the robot runs from, `updating` keeps the row on `Updating…` through the restart until the
  robot reports again, and `update_error` is the script's last line when it gave up. A robot
  that reports no commit is from before it could update itself, so it is not offered one.
- **Position** is metres since the origin, which the backend resets on the robot whenever a
  run is selected. The webapp never converts steps to metres, the robot owns the drive
  geometry and reports both.
- **Stale live data** is never shown as current: telemetry older than 2 s shows `—`, a
  detector frame older than 8 s shows `—`, and a camera tile without a new frame for 2 s
  dims its image and shows a "Not live" badge.
- **Live detections**: `vision_telemetry` arrives for every detector frame, empty ones
  included, so it doubles as the detector's heartbeat on the live screen. It carries no row
  ids, so a frame with detections only triggers a reload of the stored run; the log itself
  is always built from what the backend persisted.

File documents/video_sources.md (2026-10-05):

# Sources of stock content used in our video
Cable car:        https://www.pexels.com/video/scenic-aerial-view-of-swiss-alps-cable-car-34718592/ 
Background sound: https://pixabay.com/de/music/optimistisch-inspiring-corporate-271967/

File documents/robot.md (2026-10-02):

# Robot Infos

## Camera Stepper

# Belt
Belt Size: +2

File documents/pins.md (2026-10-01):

# Raspberry Pi 5 Pin Legend
The document contains all the used RPI pins and maps them to its corresponding cable as follows: 
Description of cable purpose: RPI pin; cable legend 

## PINS
### Stepper
* Stepper GND: 6; 000
* Motion Stepper PUL: 12 (GPIO 18); 013
* Motion Stepper DIR: 16 (GPIO 23); 012
* Camera Stepper PUL: 32 (GPIO 12); 023
* Camera Stepper DIR: 36 (GPIO 16); 022

### Buttons
* Button GND: 30; 071 
* Start Button SIG: 29 (GPIO 5): 070
* Stop Button SIG: 31 (GPIO 6): 080

# Buzzer
* Buzzer SIG: 37 (GPIO 26): 101

# I2C 
* I2C GND: 9; 004 
* I2C Vin: 1; 003 
* SDA: 3; 001 
* SCL: 5; 002

03 - Display
0: GND
1: VDD => I2C Vin
2: SCK => SCL
3: SDA => SDA

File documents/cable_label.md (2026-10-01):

# Cable Label Legend 
All cables have a label. 
The first two digits corresponds to an electronic component. 
The third digit corresponds to a specifc pin of such a component. 
## Generell: (add common gnd)
* GND: GND (common Ground)

## Components 
### 00 - Raspberry Pi 5 
* 0: GND
* 1: SDA 
* 2: SCL 
* 3: Vcc (3.3V) 
* 4: GND

### 01 - Motion Stepper Driver 
* 0: GND
* 1: GND
* 2: DIR
* 3: PUL 
* 4: GND 
* 5: Vcc (12V)

### 02 - Camera Stepper Driver
* 0: GND
* 1: GND
* 2: DIR
* 3: PUL 
* 4: GND 
* 5: Vcc (12V)

### 03 - Display 
* 0: GND 
* 1: VDD
* 2: SCK
* 3: SDA

### 04 - ToF Sensor 
* 0: Vcc
* 1: GND
* 2: SDA
* 3: SCL

### 05 - DC Step Down 
* 0: GND 
* 1: Vcc (12V)

### 06 - Battery 

### 07 - Button Red 
* 0: SIG 
* 1: GND (All buttons)

### 08 - Button White  
* 0: SIG

### 09 - Button Yellow
* 0: SIG

### 10 - Buzzer 
* 0: GND 
* 1: SIG

## Groups
* BTN: all Button signals connected: 070, 080, 090

# Notes
I^2C: display stuff connected from tof to display cable round

think about: vcc 3.3v, 5v, 12v ezt

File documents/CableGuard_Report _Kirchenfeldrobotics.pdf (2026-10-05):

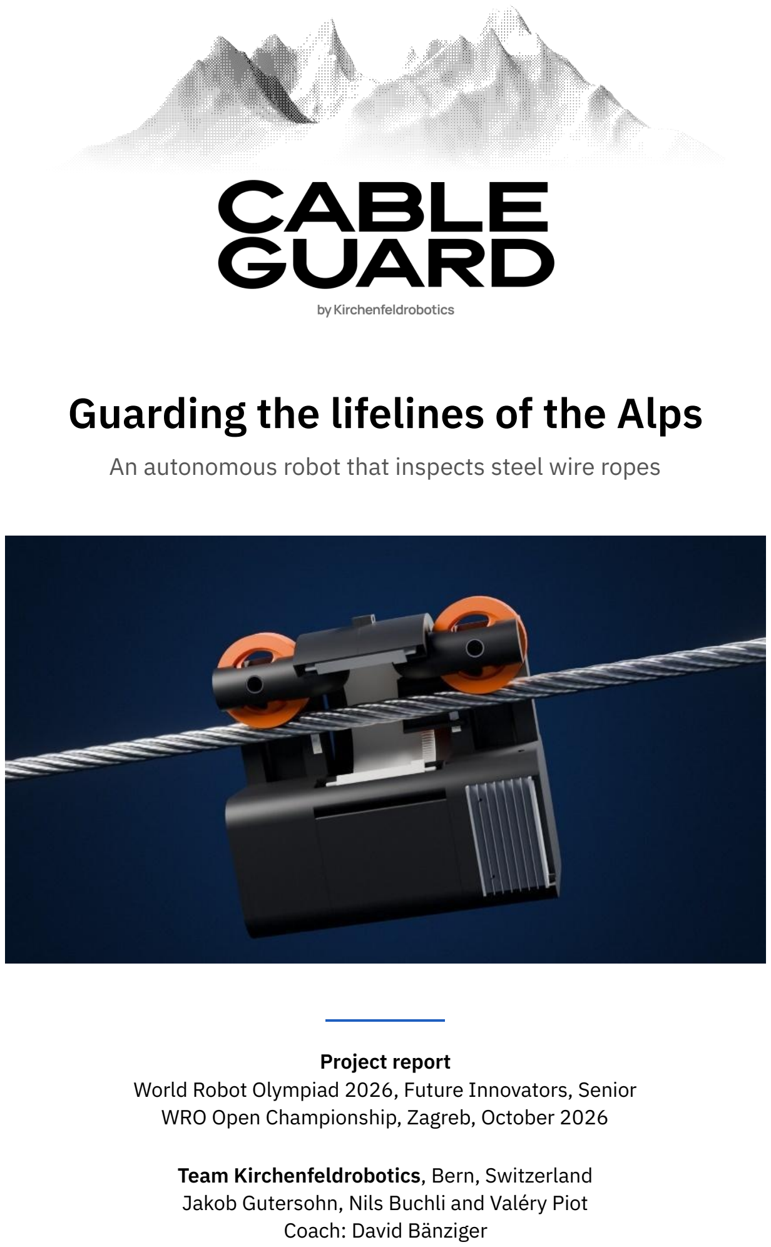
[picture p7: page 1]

# Guarding the lifelines of the Alps

An autonomous robot that inspects steel wire ropes

Project report
World Robot Olympiad 2026, Future Innovators, Senior WRO Open Championship, Zagreb, October 2026

Team Kirchenfeldrobotics, Bern, Switzerland Jakob Gutersohn, Nils Buchli and Valéry Piot Coach: David Bänziger

# Contents

### 1 Our team | 1 2 Summary of the project idea | 2

The problem | 2
Our solution | 2
What it is worth | 2

### 3 Our robotic solution | 3

3.1 How the idea developed | 3
3.2 What already exists | 4
3.3 Construction: mechanics | 4
3.4 Construction: electronics | 7
3.5 Coding | 8
3.6 Challenges and tests | 11
3.7 Use of AI | 13

### 4 Social impact and innovation | 14

4.1 Who Cableguard helps | 14
4.2 Possible negative effects | 15
4.3 A tried use case | 15
4.4 Key innovation | 16
4.5 From prototype to start-up | 16
4.6 Next steps | 18
Sources | i

Cableguard · Documentation of Kirchenfeldrobotics | WRO 2026 Future Innovators, Senior

# 1 Our team

Hi WRO, we are Kirchenfeldrobotics (kirchenfeldrobotics.ch), a registered student robotics club from Bern. All three of us are in the third year of Gymnasium Kirchenfeld.
Last year Jakob and Valéry built Farmatic, a modular vertical farm, and won 3rd place and the Team Award at the WRO Open Championship in Slovenia [1]. This season we took on something that carries lives in the Alps and is still checked by eye: the steel rope. We iterated Cableguard through three versions in one season, and on 20 June 2026 it won 2nd place at the Swiss final, which brought us to Zagreb.
We want Cableguard to outlive this competition: a robot on every historic ropeway, and every broken wire found on the day it breaks, not on the day the rope fails. Our roadmap leads from this prototype to a pilot and a company (section 4.6).

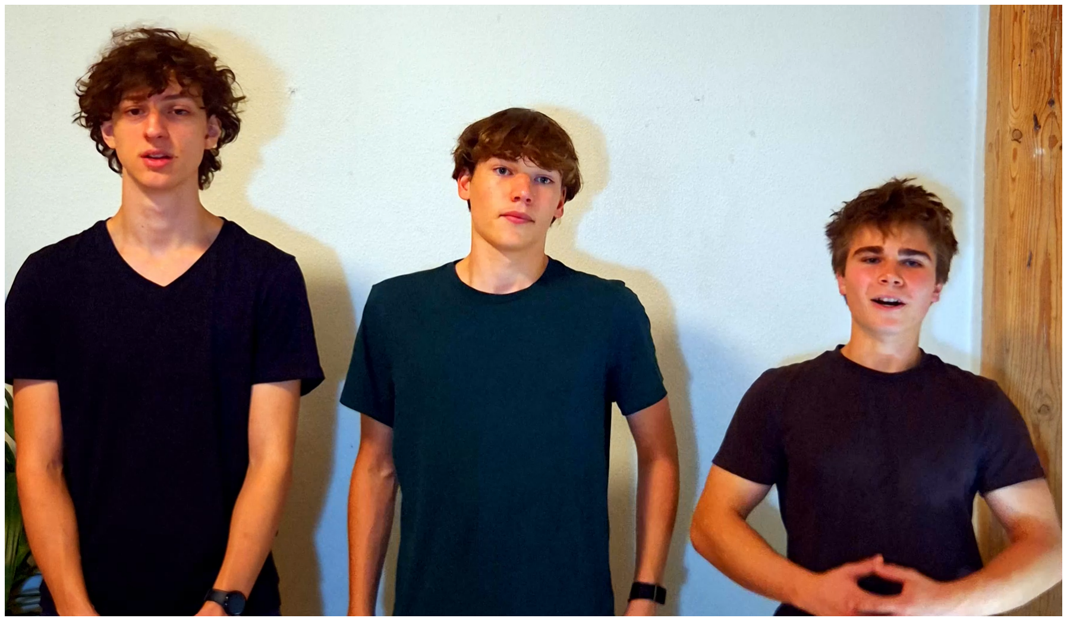
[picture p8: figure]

Figure 1. Our team with Cableguard: Jakob Gutersohn, Valéry Piot and Nils Buchli.

Member | Responsibility | In this project
Jakob Gutersohn | Hardware | Designed every custom part in CAD, assembled the robot and soldered
Nils Buchli | Software and electronics | Robot software on the Raspberry Pi and the server. Set up and tested the electronics with Valéry
Valéry Piot | Software and electronics | Web app, login, the AI model with its training and parts of the Raspberry Pi. Set up and tested the electronics with Nils and wired all components. Set up the Raspberry Pi 5 for a GitHub auto-redeploy workflow.
David Bänziger | Coach | Helped us plan and organise and reviewed our work. He won the WRO Open Championship 2025 with his own team.

Everything around the robot was shared work: all three of us wrote sponsoring requests, built the finance plan and wrote this report. Our goal is that each of us is responsible for one part and still understands the others. Since August we have written about 9,700 lines of code in more than 150 commits and 20 merged pull requests. We trained our own neural network on about 22,000 rope images, wrote a program for the Pi’s PIO hardware that times every motor step to the microsecond, and went through three hardware generations: our own ESP32 circuit board, a magnetic sensor ring with eight Hall sensors, and finally the Raspberry Pi 5. Each time we tested, changed and tested again.

1 Our team | 1 / 19

# 2 Summary of the project idea

## The problem

On 23 May 2021, shortly before the top station of the Stresa–Mottarone cable car in Italy, its haul rope snapped. The cabin rolled back, came off at a pylon and fell into the forest. Fourteen people died, and a five-year-old boy was the only survivor [21]. Court experts later found that 68 % of the wires at the break had failed from fatigue and corrosion long before that day, and that correct checks would have revealed it [29]. The rope did not fail suddenly. It weakened over years, and this is exactly the kind of slow damage that regular inspection is meant to catch.

Figure 2. Mottarone, Italy, 23 May 2021: rescuers at the cabin after its haul rope broke. Press photo.

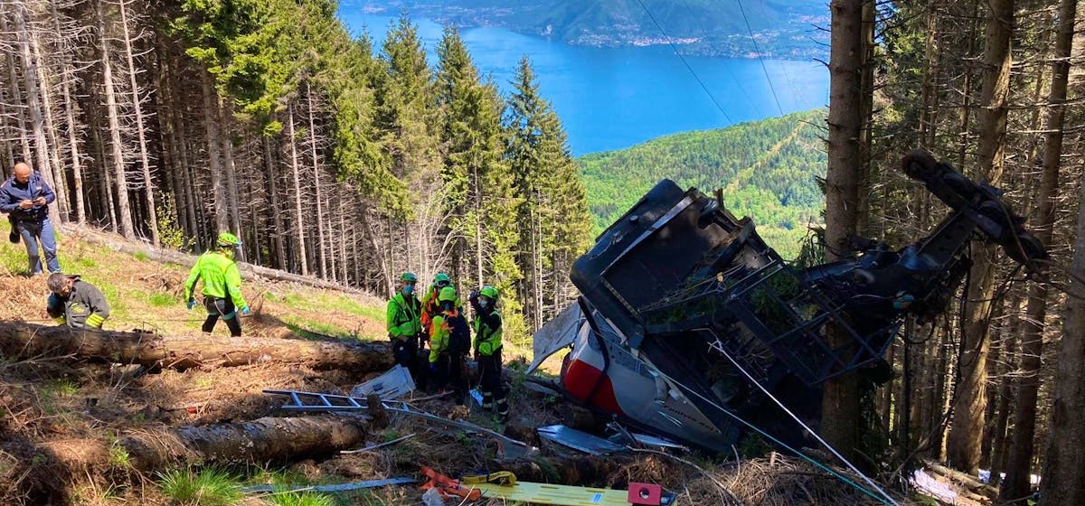
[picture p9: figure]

Switzerland has about 2,450 cableways [2]. 129 are listed as heritage [3], and every second small cableway has financial problems [4]. Their steel ropes age: wires break, corrosion and lightning leave marks [5]. Today a person checks a rope by riding on a slow-moving gondola, which is slow, expensive and prone to error [6]. Climate change adds pressure. In 2022 the Swiss permafrost reached record temperatures at two thirds of the measuring sites [33], and the ground under high-alpine stations and pylons is becoming unstable [34]. The check that saves lives has to become cheaper and more frequent, not rarer.

## Our solution

The operator places Cableguard on the rope and presses start, and the robot works alone. Two cameras on a rotating ring photograph all four sides of the rope continuously, a YOLO26 network that we trained on about 22,000 rope images marks eight classes of damage, and the steps of the motor give the position of every photo. A web app shows the session live and visualises inspections.

## What it is worth

Every finding comes with a photo and its exact position, and an operator can inspect as often as needed without a crew. Most rope damage shows on the surface. For damage inside the rope, a magnetic sensor ring can be added later (section 3.1). It covers the time between two tests, when damage like that at Mottarone grows unseen.

2 Summary of the project idea | 2 / 19

# 3 Our robotic solution

Cableguard is a self-driving inspection robot with two stepper motors, two cameras, a distance sensor and a Raspberry Pi 5. It weighs 3 kg and hangs on the rope by two wheels (Figure 3). This chapter describes how the idea changed, what already exists, how we built and programmed the robot and how we solved the overheating of the Raspberry Pi 5 caused by the neural network.

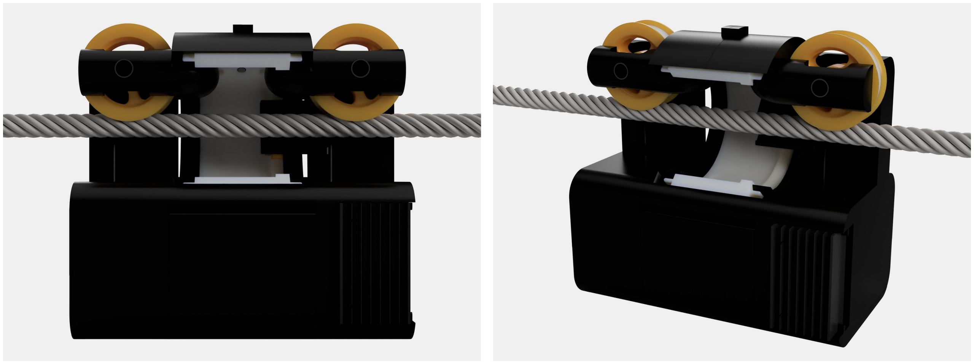
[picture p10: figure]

Figure 3. Cableguard on a rope, rendered from our CAD model.

## 3.1 How the idea developed

We have rebuilt Cableguard twice (Figure 4). Each version answered the same question in a different way: how do we find damage on a rope?

Version 1, regional final
(May 2026)

Version 2, Swiss final (June 2026)

Version 3, Open
Championship (October 2026) Finds damage
with

One camera, images
analysed on a server with
OpenCV

Magnetic flux leakage: a ring of eight Hall sensors around the rope

Two cameras on a rotating ring, YOLO26 network on the robot

Computer ESP32-S3 on our own PCB plus an STM32H7

ESP32-S3 on our own PCB Raspberry Pi 5

What we
learned

PLA wheels slip on steel.
Images sent through two
microcontrollers arrived too unreliably

The readings of the Hall
sensors were too unreliable to judge a rope

First completely reliable
solution. More about it in the rest of this chapter

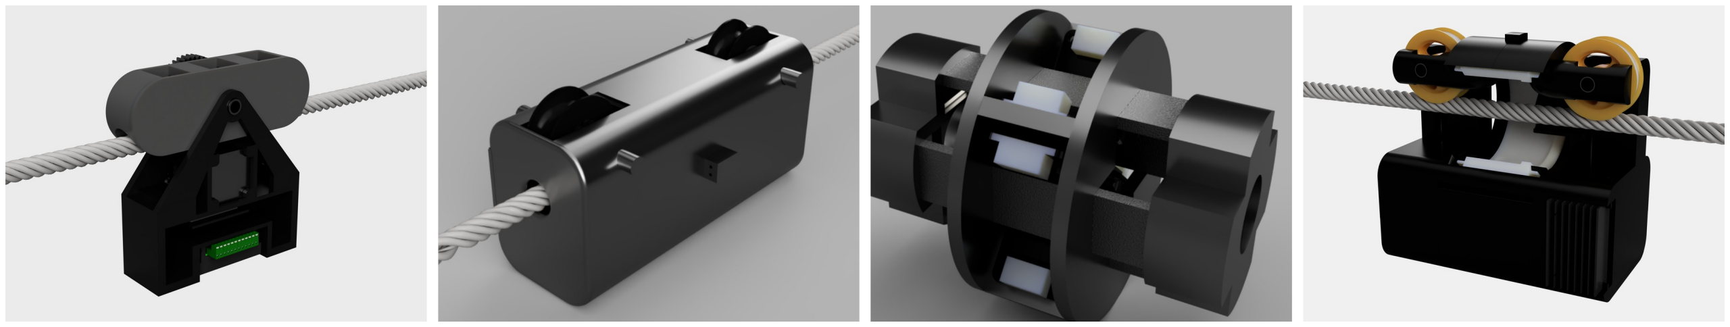
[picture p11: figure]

Figure 4. The three versions as renders from our CAD models. From left: version 1, version 2 closed, the magnetic sensor head inside version 2, and version 3.
Version 2 used magnetic flux leakage (MFL) to read the magnetic field lines with Hall sensors. MFL analyses the inside of the rope, which no camera can. We built the sensor part, a ring of eight Hall sensors that the rope passes through. Three things stopped us there. The rope has to be magnetised close to saturation by very strong magnets in an iron yoke [8], and after we reviewed this approach, we identified the main problem: such a head is hard to install “due to the
3 Our robotic solution | 3 / 19

large magnetic force between the magnet and the specimen” [8]. The yoke has to be machined from iron, and we have a 3D printer and no CNC machine. And turning the sensor readings into a statement about the rope needs a model of the magnetic field, which means solving Maxwell’s equations for the rope. Our readings were too unreliable for that.
After the Swiss final we made cameras the main sensor, for three reasons. We can build a camera system ourselves. A photo is evidence that anyone can check, while a magnetic signal gives data for a trained inspector. And thousands of labelled photos of damaged ropes are public, so we could train a network on images from different environments, so that our model is not overfitted to a small dataset of our own images. A working camera robot is also the prototype we need to find partners and funding for the magnetic head. The camera is also extremely reliable and works in most cases. It is almost as reliable as magnetic flux leakage, because damage that makes a steel rope dangerous has to be big, and we can also detect deformations of the rope, so the camera indirectly shows a defect inside as well.
The magnetic idea stays in the design as an upgrade. The software sorts every finding into the two groups of magnetic testing, local faults (LF) and loss of metallic area (LMA), the same two groups in which the European rope standard EN 12927 reports a magnetic test [28], and the protocol has a message for findings from a second sensor. In August we started the software again from an empty repository, now for a Raspberry Pi 5, and wrote version 3.

## 3.2 What already exists

Method | How it works | Strength | Limit
Visual inspection by a person | An inspector rides on a slow-moving gondola and inspects by eye | Finds scratches, notches and early corrosion that the magnetic test misses [5] | Slow, depends on the inspector, leaves no photo [6]
Magnetic rope testing | Magnets magnetise the rope, sensors measure the field that leaks out at a defect [8] | Finds broken wires inside the rope [5] | Needs a testing body. The result is a curve without a picture and extremely expensive
Camera systems of testing institutes | Four cameras around the rope, a measuring wheel gives the position [9] | Photos as evidence, software measures diameter and lay length [5] | Expert equipment that a testing body brings and operates and extremely expensive
Cableguard | Drives along the rope with two cameras on a rotating ring and a network on board | Works alone, photo and position for every finding, compares inspections | Sees the surface. But with our network we can see inside indirectly (section 3.1)

A magnetic signal is “only a 1D image of the real damage”, every doubtful signal has to be checked by eye, and the rope ends are not tested magnetically at all [27]. That confirmed our plan: cameras first, the magnetic head later, both on the same robot. Cableguard differs from the systems above in three points. It is meant to belong to the operator, it uses two cameras and a motor in place of four cameras, and its network decides how fast it drives.

## 3.3 Construction: mechanics

The body of the robot hangs below the rope. Two wheels on top carry it, and the rope passes through the upper part of the casing, where a ring with the two cameras surrounds it (Figure 5).

Property | Value
Size of the casing | 277 x 160 x 245 mm
Weight | 3 kg
Visualisation rope | Steel rope, 22 mm diameter, 1.6 m long
Scan speed | About 3 cm per second, calculated in section 3.5
Power | 3S LiPo battery

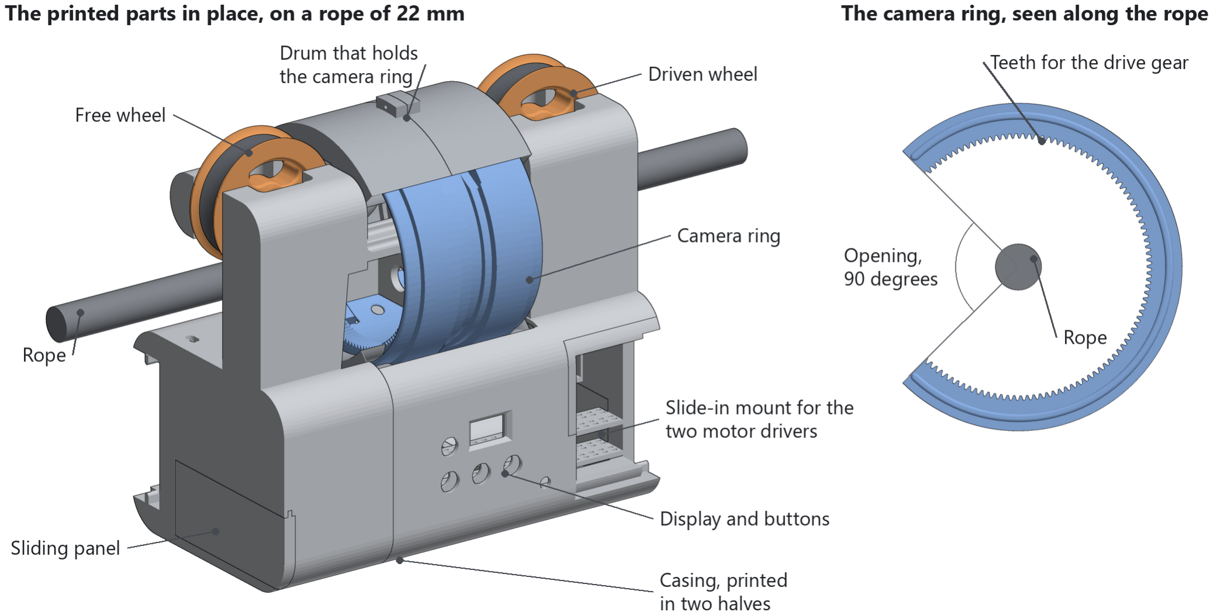
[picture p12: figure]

Figure 5. The printed parts of the robot and the camera ring, drawn from our CAD model. Motors, belt, cameras and electronics are not shown.
Drive
The robot rides on two wheels. A NEMA 23 stepper motor drives one of them through a GT2 belt with a printed tensioner, and the second wheel runs free. The first wheels were printed from PLA and slipped on the steel. The current wheels have an insert of flexible TPU with a V-shaped groove (Figure 6). The weight of the robot presses the rope into the V, and this wedge gives the grip that a flat wheel does not have.

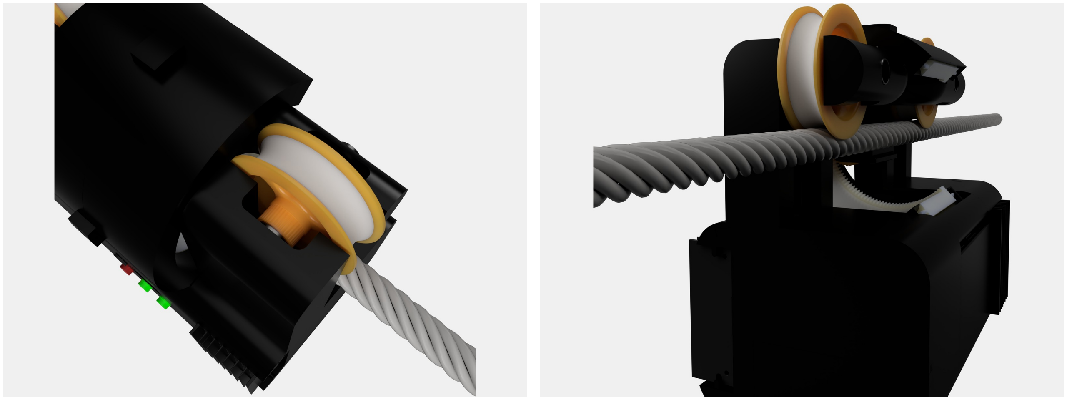
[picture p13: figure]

Figure 6. A wheel on the rope, seen from two sides.
We chose a stepper motor because it moves in fixed steps, 200 per turn, each split into 8 mi-crosteps by the driver. The robot counts every microstep it sends, so it knows its position without an extra sensor, and one step is a fraction of a millimetre on the rope. The weakness of counting steps is slip: if the wheel slips, the robot believes it is further along the rope than it is. We have not measured slip yet, but we have a solution for it: later, the robot could correct this error itself by comparing its own photos and GPS position, without any marks on the rope. We decided not to use GPS for the position itself, because it is only precise to roughly 3 to 10 m, which is not as precise as the steps of the robot, so we use steps. However, GPS is planned for a future pilot to calculate the error of the step count.
Why a camera ring
A rope is round, and one camera sees less than half of it. Near the edge of the picture the surface curves away and the wires become too narrow to judge. The testing institutes therefore mount four cameras around the rope [9].
We wanted the same coverage with fewer parts. The Raspberry Pi 5 has two camera connect-ors [11], and every further camera adds a cable, weight and a picture for the network to process. So two cameras sit opposite each other on a ring, and a second NEMA 23 turns the ring through a printed gear (Figure 7). The cameras take a pair of photos, the ring swings them 90 degrees, and they take a second pair of the two sides that were hidden.

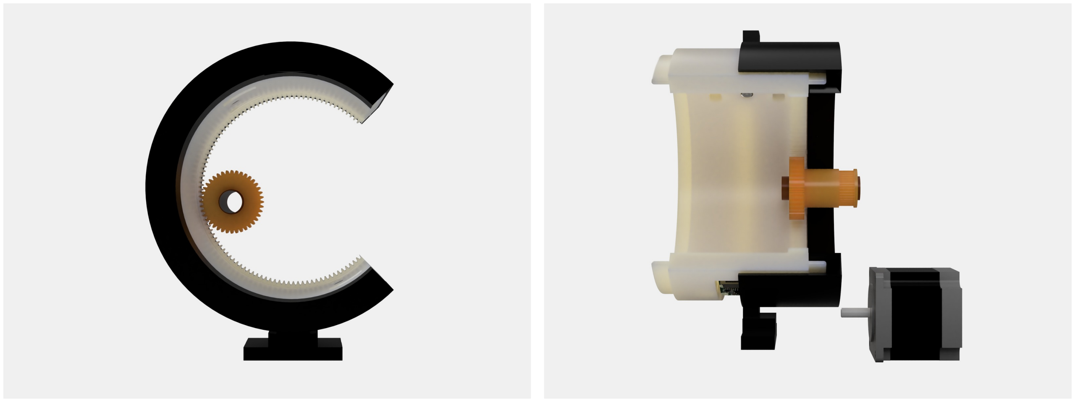
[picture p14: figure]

Figure 7. The camera ring (white) with its inner teeth and the gear that turns it. Right: the same unit from the side with its motor.
The ring has an opening of 90 degrees. To put the robot on a rope, the ring turns to its open position, the rope slips through the opening into the centre of the ring and the wheels come to rest on the rope. Two rules follow from the hardware. The ring always swings back the way it came, because the cameras hang on their cables and a ring that kept turning would wind them up. And since the ring has no end switch, whoever sets up the robot leaves it at its parking angle and the software counts every step from there.
Casing and material
Every structural part is 3D printed in PLA: both halves of the casing, the drum that holds the camera ring, the wheel hubs and all mounts, 16 pieces in total. Only the axles, spacers, screws and belts are bought parts. We print because we can redesign a part ourselves and test it a day later, without a workshop.
The casing is a prototype. It encloses the electronics (Figure 8), but it has no seals, and we have not tested it in rain or frost yet. PLA also softens at about 57 °C [12], which a dark casing can reach in the summer sun. For a robot in weekly use we plan a casing of ASA or aluminium with sealed openings (section 4.6). The design stays the same for that step. Only the material and the seals change.

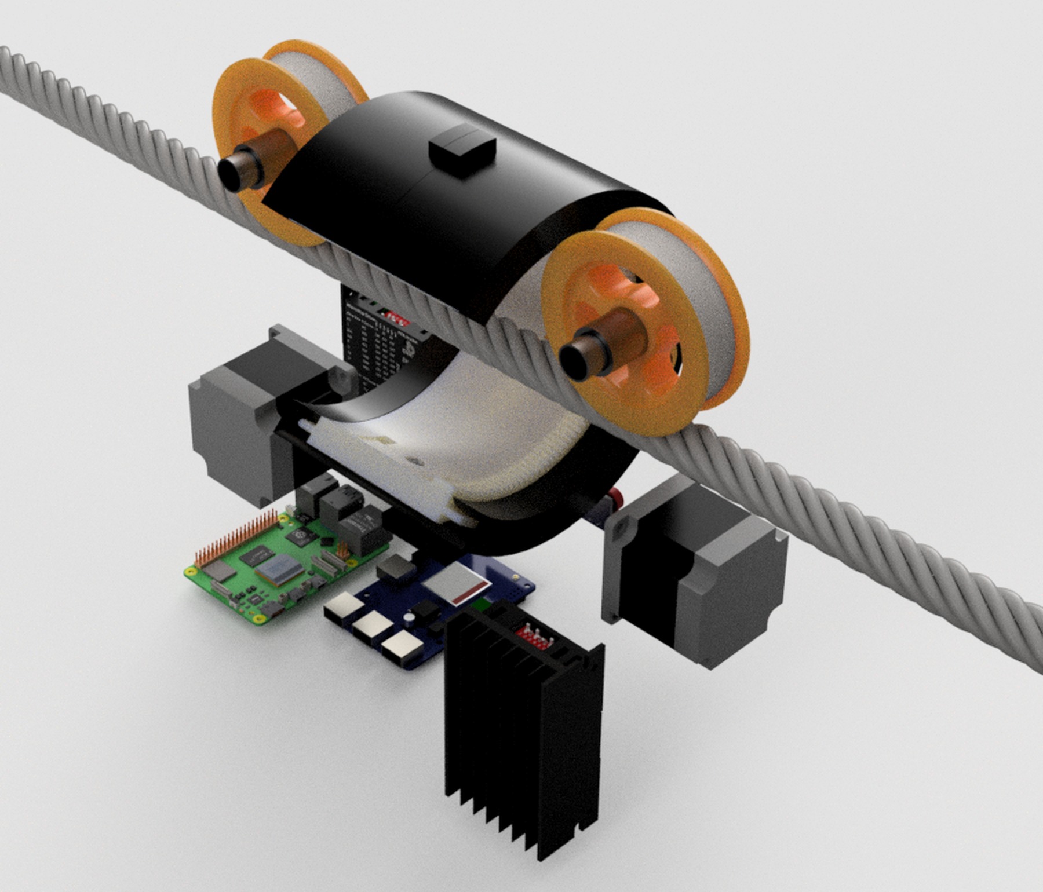
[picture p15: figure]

Figure 8. Inside Cableguard with the casing hidden. The rope runs through the drum with the camera ring, the motors and the electronics hang below it.

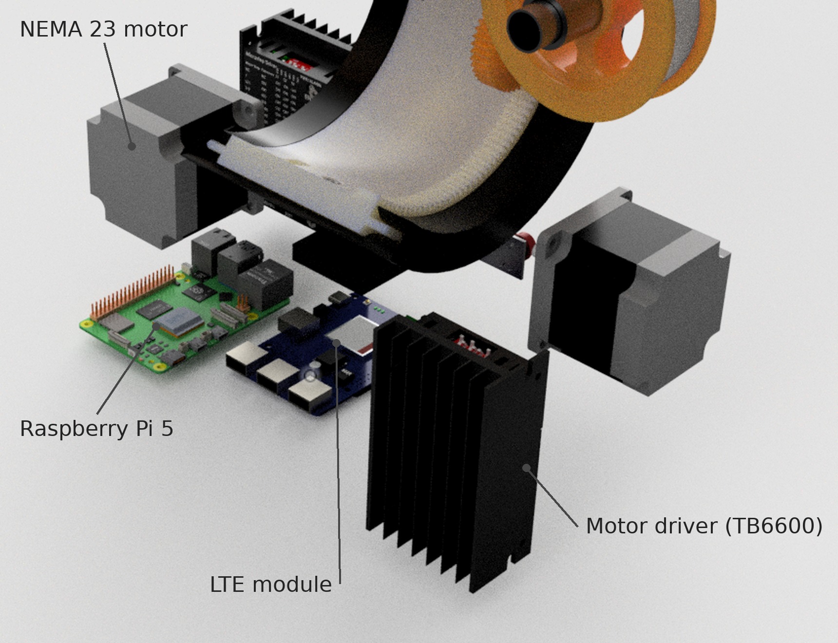
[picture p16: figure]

Figure 9. The electronics below the camera ring. Each motor has its own TB6600 driver.

## 3.4 Construction: electronics

One Raspberry Pi 5 runs everything on the robot (Figure 9): both motors, both cameras, the neural network and the connection to the server. In version 1 this work was split between two microcontrollers that had to talk to each other over a serial cable.

Component | Part | Connected to
Computer | Raspberry Pi 5
Drive motor | NEMA 23 stepper motor with TB6600 driver | Step GPIO 18, direction GPIO 23
Ring motor | NEMA 23 stepper motor with TB6600 driver | Step GPIO 12, direction GPIO 16
Cameras | 2 x Raspberry Pi Camera Module 3 Wide with LED light | Both camera ports of the Pi
Distance sensor | TOF200C (VL53L0X laser sensor) | I2C bus
Display | 0.96 inch OLED, 128 x 64 pixels | I2C bus
Buttons and buzzer Red start button, white stop button, buzzer. A
| third button is wired and has no function yet | GPIO 5, 6 and 26
Mobile link | LTE module with SIM card
Power | 3S LiPo battery (11.1 V nominal) and step-down converter | Battery voltage directly to the motor drivers, 5 V from the converter to the Pi

Three decisions shaped the wiring.
One computer. A neural network needs a real processor, and the Pi 5 has the two camera ports and the GPIO pins we need [11]. A photo, the motor position at that moment and the result of the network now live in one program, and nothing has to be synchronised over a cable.
Usable without a phone. Three buttons, a buzzer and a small display are enough to start a run, stop it and see what the robot is doing. Each state has its own sound, and the display shows connection, position and speed. The Pi pulls both button pins high from the moment it boots, so a button held down during start-up cannot start the motor.
Cables that explain themselves. Three voltage levels, 12 V, 5 V and 3.3 V, meet in a small space. Every cable carries a three-digit label with two digits for the component and one for the pin. 013 is pin 3 of the drive motor driver, its step input. One file in the repository maps every label to a pin of the Pi.
The sensor ring of version 2 with its eight Hall sensors is not on the robot. We kept it, and section 4.6 describes how the magnetic head could come back.

## 3.5 Coding

The software runs on three devices. The robot inspects on its own, the server stores every finding and the web app is the window for the operator (Figure 10). We wrote in Python, TypeScript and
C. Everything else we use is open source and free for everyone: FastAPI, Next.js, Ultralytics YOLO, NCNN and the Raspberry Pi libraries for the cameras and the PIO block.
The robot inspects alone, the server stores, the web app shows

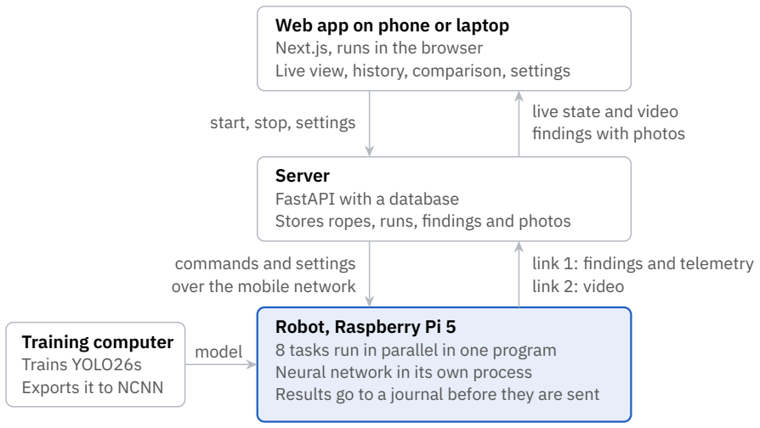
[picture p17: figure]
Web app on phone or laptop Next.js, runs in the browser Live view, history, comparison, settings; Server FastAPI with a database Stores ropes, runs, findings and photos; Robot, Raspberry Pi 5 8 tasks run in parallel in one program Neural network in its own process; Training computer Trains YOLO26s Exports it to NCNN; start, stop, settings; live state and video; findings with photos; commands and settings over the mobile network; link 1: findings and telemetry link 2: video; model

Results go to a journal before they are sent

Figure 10. Software architecture: three devices and two links from the robot to the server.

One scan cycle
1. Both cameras take a photo while the ring stands still.
2. The ring swings 90 degrees. During the swing the on-board AI model analyses the two photos.
3. Both cameras take a second photo of the two sides that were hidden.
4. The ring swings back and the network analyses the second pair.
5. Every result is written to a journal with the position of the robot at the moment of the photo. Only the shutter needs a ring that stands still. The network can work while the cameras move, so turning and analysing happen at the same time (Figure 11).
The robot sets its own speed
In the first weeks the operator chose the speed in the web app. A robot that drives faster than its network can analyse leaves stripes of rope that nobody looks at, so now the robot measures itself. At every start it runs nine test cycles and times the cameras and the network separately. One photo covers a length L of rope, and the robot may travel exactly L per cycle.
What the robot calculates | Formula
Time for one quarter turn | tturn = max(︂

H · D
R

, t

ring)︂

Time for one cycle | T = R ·

(︂

| C R + tturn)︂
Driving speed | v = L T

C is the camera time and D the network time of one cycle, R = 2 the number of photo rounds and

t

ring the fastest quarter turn of the ring. H = 1.5 is a safety factor, because the network needs longer

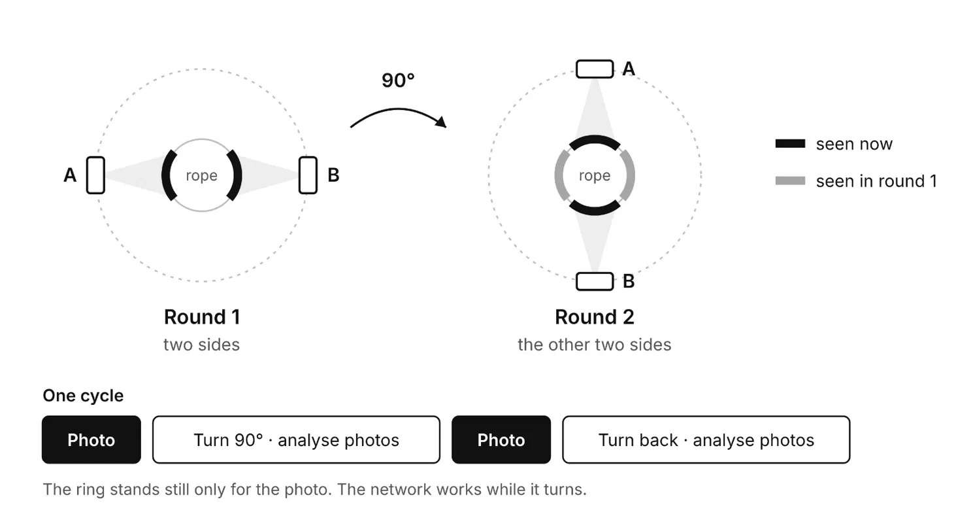
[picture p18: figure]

Figure 11. Scan cycle of the camera ring: two rounds of photos and one quarter turn.
for a photo with damage than for the clean rope it was timed on. An example: with L = 60 mm, C = 0.14 s and D = 1.2 s, which is 0.3 s per photo, the cycle takes T = 1.94 s and the robot drives 31 mm per second, about 110 m per hour. The operator only chooses start, stop and the direction. But we can easily scale this up with a more capable computer like an NVIDIA Jetson Orin Nano (roughly CHF 300), which has a GPU optimised for matrix computations and runs the AI model faster.
Knowing the position
A finding is only useful with its position, and the position is the count of motor steps. Every pulse has to arrive on time, also while the processor is busy with the network. Our first driver made the pulses in Python, and the motor stuttered whenever the network ran.
The Raspberry Pi 5 contains a hardware block called PIO, four small state machines that run independently of the processor [13]. We wrote a program of seven instructions for it and a small C library around it. The software hands the hardware a block of pulses, and the hardware plays it with a resolution of one microsecond. The robot adds a block to its position only after the hardware reports it as played, so the count cannot run ahead of the motor.

.side_set 1 opt
.wrap_target
pull block | side 0 | ; wait for a block, STEP stays low
out x, 16 | | ; x = steps - 1, OSR keeps the low-time count
step:
mov y, osr | side 1 [7] | ; STEP high for 10 cycles
nop | [1]
low:
jmp y-- low | side 0 | ; STEP low for y + 1 cycles
jmp x-- step
push noblock | | ; block done
.wrap
The complete program of the PIO block for one stepper motor, from robot/src/motion/stepgen.c.

The neural network
We use YOLO26s, an object detector with 9.5 million parameters that was released in January 2026 for small computers without a graphics card [14]. It draws a box around every damage and gives a score of how sure it is.
For training we merged two public collections of rope photos [15] [16] with a script that unifies their class lists. The merged set has about 22,000 images with 37,513 marked damages in eight classes. We trained for 150 rounds on a graphics card and converted the result to NCNN, a format that runs fast on the ARM processor of the Pi. On the validation photos, which were not used for training, the network finds 96 % of all marked damages, and 74 % of its boxes are real damages. Mean AP50 is 0.68, the two weakest classes lose their detections to a twin name
Average precision per damage class at IoU 0.5 on the validation set, first training run
AP50, from 0 to 1 | mean 0.68 | marked damages in the data
Wear | 0.95 | 11,547
Kink | 0.92 | 346
Bird caging | 0.87 | 488
Unknown defect | 0.72 | 580
Broken wire | 0.69 | 10,054
Mechanical damage | 0.55 | 3,326
Thunderbolt | 0.48 | 4,025
90 % of the true thunderbolt boxes are predicted as mechanical damage
Break | 0.28 | 7,147
86 % of the true break boxes are predicted as broken wire

Figure 12. Validation results of our first training run on 13 September 2026.
Two decisions follow from these numbers. The robot reports a box as soon as the network is 10 % sure. A false alarm costs the operator one look at a photo, and a missed broken wire can cost much more. And it reports each damage in the two groups that rope inspectors know, local fault and loss of metallic area. Figure 12 shows why that helps. The network confuses “break” with “broken wire” and “thunderbolt” with “mechanical damage”, because the two photo collections use different names for the same damage. All four are local faults, so the report of the robot stays correct.

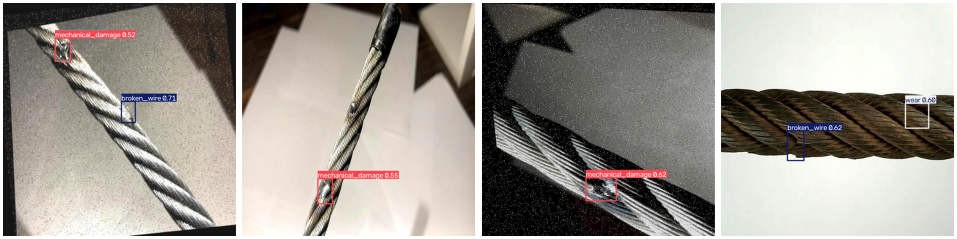
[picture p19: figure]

Figure 13. Four photos from the public test set with the boxes and confidence values of our network.
The network runs as a separate program. Before that change every analysis froze the whole robot for a few hundred milliseconds, including the thread that feeds the motor.
These numbers come from photos of other people’s ropes. On our own test rope the detection works well in our runs (section 4.6).

Passing a rope socket
A rope ends in a thick metal fitting, the rope socket, and the camera ring cannot turn past it. A laser distance sensor looks ahead. While the robot still stands it averages ten readings to learn what the sensor normally sees. When something appears 10 cm nearer than that, the ring parks at the one angle that leaves room for the socket and the network pauses. 50 cm after the last sighting the ring closes and the scan continues. A tower is passed the same way (section 4.3). Server and web app
The robot keeps two connections to the server, one for commands and results and one for video, so a video frame cannot delay a stop command. Every result is written to a journal on the memory card before it is sent, and after a connection loss the robot continues at the byte where it stopped. If the connection breaks while the robot drives, it stops and sounds the fault signal, because nobody could stop it remotely.
The web app shows both camera streams, position and speed live, keeps every inspection of a rope and compares two of them. Findings less than 1.5 m apart count as the same damage, so the operator sees what is new and what has disappeared. Operators log in with a password or by holding their phone to an NFC tag on the robot.

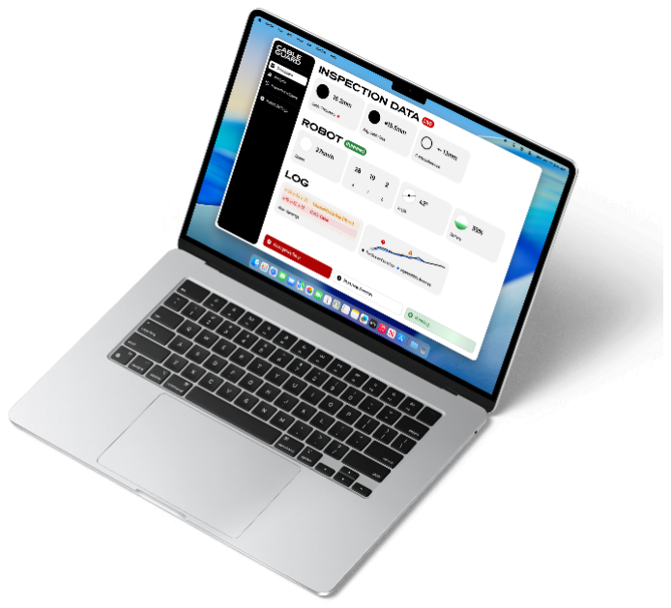
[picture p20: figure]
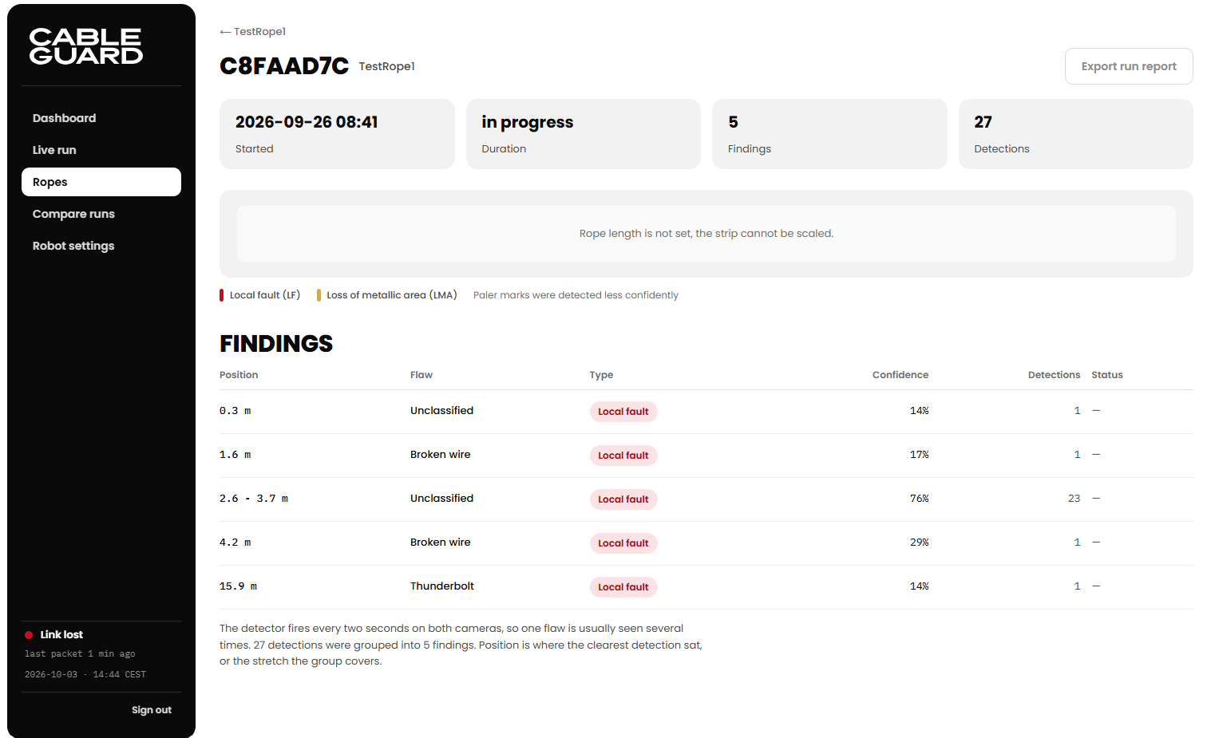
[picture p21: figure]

Figure 14. The web app: the dashboard on a laptop and the findings of one run with position, flaw and confidence.

What the robot decides by itself

Decision | What it is based on
Driving speed | Its own timing test at start-up
Speed of the ring | The time the network needs for one pair of photos
Open and close for a rope socket or a tower | Distance sensor compared with its own calibration
Pause the network | Standing still, which keeps the processor cool
Stop | Connection lost while driving
Accept new settings | Only when the drive stands and the ring is parked

## 3.6 Challenges and tests

Six problems shaped the current design, besides the magnetic head (section 3.1) and the two unseen sides of the rope (section 3.3).

Problem | What we saw | What we changed
Wheels slip | Printed PLA wheels slipped on the steel rope | TPU insert with a V-shaped groove that the rope is pressed into
Motor stutters | Pulses from Python came late whenever the network ran | Pulses from the PIO hardware block
Network freezes the robot | Every analysis blocked all other threads | Network in its own process
Rope is skipped | The operator could drive faster than the network could analyse | The robot sets its own speed
Photos unusable | Automatic exposure changed the brightness, the focus was wrong | Fixed exposure, gain and white balance, focus locked at 5 cm
Position jumps | New drive settings during a ramp changed the meaning of counted steps | Settings apply only while the robot stands

We test on our own rig (Figure 15), a steel rope of 22 mm diameter and 1.6 m length. There we run complete inspections: start by button, scan with the swinging ring, findings in the web app, stop. Two scripts test the connection to the server from the side of the robot and from the side of the browser, and the detector can be tested alone on a laptop with a webcam.

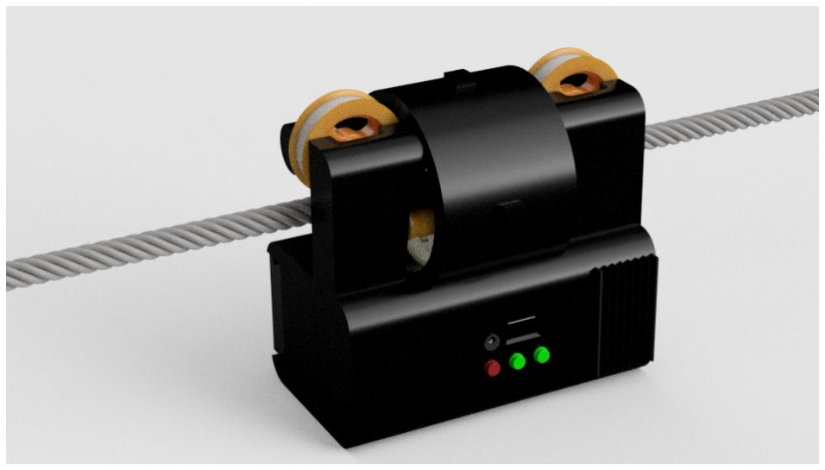
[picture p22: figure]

Figure 15. Cableguard on a 22 mm rope like the one on our test rig, seen from the side with the buttons. Rendered from our CAD model.
What is still missing are measurements. We have not yet measured the position error over distance, the hits and misses on prepared damage, the battery runtime, the steepest slope the robot can climb or the behaviour in rain and frost, and we have no automated software tests.
Two estimates we will check first. Our test rope is level, but many small cableways are steep. On a slope of 30 degrees the driven wheel has to pull about 15 N (3 kg × 9.81 m/s² × sin 30°), while only about half of the weight presses it onto the rope. We will tilt our rig until the wheel slips. If the angle is too low, both wheels will be driven or a spring-loaded roller will press the rope from below. The battery is the second question. The Pi 5 needs about 7 W while the network runs, and two NEMA 23 motors on TB6600 drivers can need 10 to 20 W each, also while they hold still. With 30 to 45 W, a 3S battery of 5,000 mAh (about 55 Wh) would last only one to two hours. We will measure the real consumption with a power meter. If the estimate holds, we will lower the holding current of the ring motor while it stands or use a larger battery.

## 3.7 Use of AI

AI system | What we used it for | How much
YOLO26s (Ultralytics) | Part of the robot. Finds damage in the camera images | We trained it ourselves on public images and integrated it into the robot
Claude Code (Anthropic) | Agentic coding assistant | Used mainly for the web app in a spec-driven workflow: we wrote detailed specifications with acceptance criteria, an agent implemented each change on an isolated feature branch, and every change was merged only through a pull request after human code review. We also used it for debugging and for root-cause analysis of stack traces, logs and race conditions between processes. Hardware-level code such as the PIO stepper driver and the camera ring was written mostly by hand, because it only became reliable through iteration on the real hardware.

Claude (Anthropic) Grammar check of this

| report, because we are not native speakers | Claude checked our spelling in English and fixed mistakes and made the text more fluent and readable.

# 4 Social impact and innovation

## 4.1 Who Cableguard helps

Operators of small cableways. Switzerland has about 250 small cableways with a cantonal licence [4]. The control office of the intercantonal concordat (IKSS), to which 21 cantons and Liechtenstein belong, checks them regularly [31], and the safety upgrades it demands can cost an operator up to half a million francs [17]. Cableguard takes over one recurring task, the visual check of the rope, and turns it into data that the operator owns.
The people who inspect. Today a person watches the rope by eye from a slow-moving gondola. With Cableguard that person reviews the photos the robot has marked and decides what to do. The judgement stays with a human and the hours of watching go to the robot.
The heritage. Central Switzerland, and Nidwalden above all, is seen as the cradle of cableway building and has the highest density of small cableways in the world. About 20 % of the Alps are reached only by these small cableways [4]. One example is the line from Fell to Spis in Nidwalden. It has run since 1932, was first driven by water and leads on to the Spis–Sinsgäu line in Wolfenschiessen, which the cableway builder Niederberger built in 1945 [4]. Lines like these are why we built Cableguard. A rope that is replaced at the right time keeps such an installation running, and every inspection adds photos to its record. This serves UN target 11.4, to “strengthen efforts to protect and safeguard the world’s cultural and natural heritage” [18].
Passengers. Rope failures are rare, but each one is a disaster. The deadliest cableway accident in Swiss history happened on 12 July 1972 between Betten and Bettmeralp in Valais: the haul rope broke because of rust, although it had been inspected regularly, and twelve people died [35]. At Mottarone in 2021 a haul rope that fatigue and corrosion had weakened for years broke and 14 people died (section 2) [21] [29]. On 3 September 2025 the cable of the Glória funicular in Lisbon, a national monument opened in 1885, broke and 16 people died [19] [20]. It did not meet the operator’s specifications and was not certified for passenger transport [30]. Three accidents and 42 deaths, and each time the rope was the part that failed.
In none of these cases did the damage appear overnight. Rust and broken wires grow over months and years. A magnetic test by a testing body happens only every few years. In Austria, whose rules follow EN 12927, the limit is three years for a haul rope and up to six years for a track rope [36]. Between two tests the rope is checked by eye, and that check leaves no record that the next one could be compared with. Cableguard works in exactly this gap. It photographs the whole rope as often as the operator wants, and the web app shows which findings are new since the last run. Damage that grows slowly then shows up as a change between two runs.
4 Social impact and innovation | 14 / 19

## 4.2 Possible negative effects

Risk | What we do about it
False safety: an operator reads “no findings” as “the rope is healthy” | Every inspection report will state its limits: surface only, free rope length only. Cableguard adds to the magnetic test by an accredited body and never replaces it
Missed damage: on the validation photos the network misses 4 % of the marked damages | Low reporting threshold, a human reviews every photo, and we retrain with our own photos
The robot as a hazard: 3 kg hang on a rope above the ground | It runs only while the installation is closed. A catch that holds the robot if a wheel leaves the rope is one of our next steps. It can automatically run in the night.
Jobs: less inspection work for people | The legally required tests stay with the testing bodies. The work of the operator shifts from watching the rope to judging findings
Data: photos and findings of an installation sit on a server | Access only with a login. The operator owns the data, and the server can run at the operator’s site

## 4.3 A tried use case

A run on our test rig, a steel rope of 22 mm, looks like this. We turn the camera ring to its open position, hang the robot on the rope and press the red button. The robot times its network, sets its speed and starts to drive. The ring swings back and forth, and both camera pictures appear live in the web app together with the position. Every finding shows up with its photo and its position on the rope. The white button stops the run.

Figure 16. The control side of the robot. Two buttons and a display are all an operator needs to start and stop a run. Rendered from our CAD model.

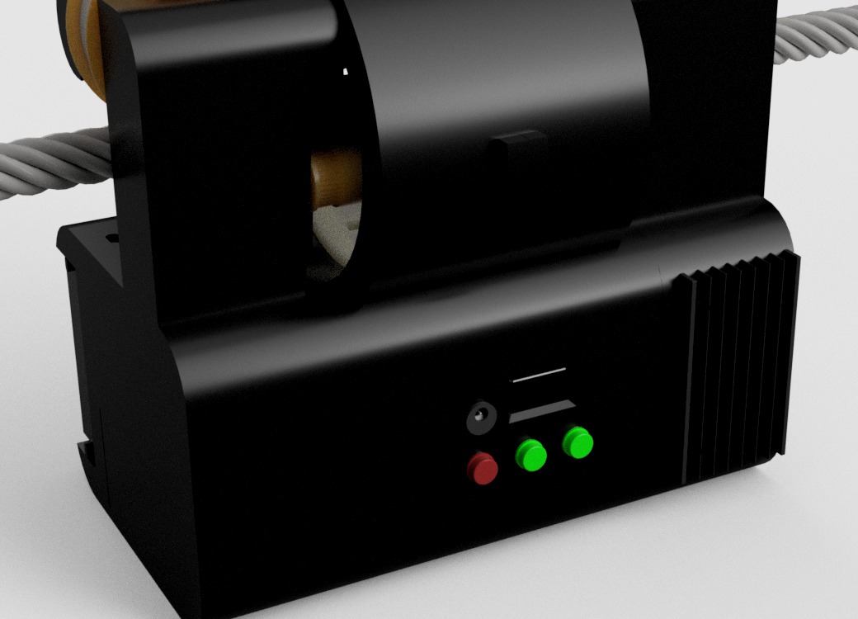
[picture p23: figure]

On a real installation the same run would happen after the last ride of the day. By our calculation the robot covers about 110 m per hour, so 800 m of rope take a little more than seven hours. That fits into one night only with a larger battery or a battery change (section 3.6). In the morning the web app lists the findings with photo and position and marks which ones are new, and the operator decides which spots to look at before the first passengers arrive.
Cableguard works in two modes, because a cableway has two kinds of rope.
A track rope never moves, so the robot drives along it. A long track rope is often made of several pieces, because it cannot be spliced. The pieces are joined by rope sockets: thick metal sleeves into which the wire ends are cast and which are bolted together. A socket is much wider than the rope, so a closed ring could not pass it. Cableguard’s camera ring therefore has an opening of 90 degrees. A laser distance sensor looks ahead, and when something appears 10 cm nearer than the rope it calibrated on, the ring turns its opening towards the obstacle, the network pauses and the robot drives on. 50 cm after the last sighting the ring closes and the scan continues. At a tower the robot uses the same routine: the track rope rests in a rope support that is held by a
4 Social impact and innovation | 15 / 19

single arm from one side, and the arm slides through the opening. One run can therefore cover a track rope along its whole length.
A haul rope is an endless loop that runs around the wheels in the stations. Here the robot drives against the direction of the rope, so it stays at the station with only its camera ring working, while the operator runs the rope slowly through it.

## 4.4 Key innovation

Our slogan is Guarding the lifelines of the Alps.
1. The robot paces itself by its own network. It measures how fast it can analyse and drives exactly that fast. An operator cannot make it skip rope by driving too fast.
2. AI on the robot, not in the cloud. The network runs on the Pi itself, so the analysis works even without a connection.
3. A rope gets a history. Every finding has a photo and a position, and two inspections are compared automatically.
4. The price. The parts of the prototype cost about CHF 400 (section 4.5).

## 4.5 From prototype to start-up

We may want to turn Cableguard into a company. This section shows what the project has cost, what one robot costs, who would pay for it and what we need to get there.
CHF 2,240 of our CHF 6,965 budget are still open
Finance plan of the Cableguard project in Swiss francs, as of 2 October 2026
Material | +465
Trip to Zagreb, 4 people | +6,400
Meals | +100
Total cost | 6,965
Prize money BärnHäckt 2026 | −375
Travel grants WRO Switzerland | −3,350
Sponsoring | −1,000
Still open | 2,240

Red bars are costs, green bars are money we have, grey bars are totals. Figure 17. Finance plan of the team on 2 October 2026.
The robot itself is cheap: all material of this season cost CHF 465, including the Hall sensors and magnets of version 2 (Figure 17). We thank the Lions Club and WRO Switzerland for their support. We have also contacted rope and ropeway manufacturers and mountain railways, the same companies we need as partners for a pilot.
4 Social impact and innovation | 16 / 19

Business model on one page

Customers Operators of small cableways in Switzerland, about 250 installations. Later larger ropeways, then cranes, elevators and bridges. | Value A rope inspection without a crew, as often as the operator wants. A photo and a position for every finding, and a comparison with the last inspection. | Revenue Estimated: Inspection as a service at CHF 400 per rope. Subscription at CHF 1,800 per robot and year. Later the magnetic head as an upgrade.
Channels Direct contact with operators. One pilot installation as our reference. | Customer relationship Web app, model updates and a replacement robot as part of the subscription. | Costs Parts of about CHF 600 per field robot, a SIM card, the server and our time.
Key resources The robot design, about 9,700 lines of software, the trained network and a growing collection of rope photos. | Key activities Build robots, train the network, run inspections and support operators. | Key partners A pilot operator, a testing body and a workshop for the magnetic head. All three are still to be found.

The nine fields of the business model canvas for Cableguard. The prices are planning assumptions.
Cost structure
The parts of one robot cost about CHF 400.
Parts of one robot | Cost in CHF
Bought this season: two camera modules with cables, LTE module, distance sensor, filament, steel rod for the axles | 186.10
From our stock: Raspberry Pi 5, two NEMA 23 motors with drivers, battery, converter, display, buttons, buzzer, belts, screws | about 210
Total | about 400
A field version with better material, seals and more durable parts would cost about CHF 600 per unit. Its development also costs more. The running costs per robot are a SIM card with a data plan and a share of the server. The largest cost of a company would be our own time, which we do not pay ourselves today.
One more cost is the licence of the network software. Ultralytics YOLO is published under the AGPL-3.0 licence, which is fine for WRO and for open software. A closed commercial product needs the paid Enterprise licence of Ultralytics, which is priced individually by the size of the company and the use case [32]. For a small start-up like ours this should stay affordable. The alternative is to publish our own code under the same AGPL-3.0 licence [32].
Customers
We start where we live. Switzerland has about 2,450 cableway installations, about 660 with a federal licence and the rest under the cantons [2]. Our first customers are the roughly 250 small cableways, where every second operator has financial problems [4]. The market abroad is large. The Doppelmayr/Garaventa group alone has built more than 15,700 installations in 97 countries [22]. One study values the market for cable cars and ropeways at USD 5.5 billion in 2024 and USD 11.2 billion in 2032, driven by cable cars in cities [23]. Cranes, elevators and bridges use the same ropes and are a later market.
We did the math for our first market ourselves. If each of the 250 small cableways had one rope inspected per year at CHF 400, the market would be about CHF 100,000 a year. That is enough to start, but not enough for a company. We therefore see three circles: the 250 small cableways as the market we can reach first, all 2,450 Swiss installations including the 660 with a federal licence
4 Social impact and innovation | 17 / 19

as the market our product can serve, and ropeways, cranes, elevators and bridges worldwide as the whole market.
Many small cableways have little money, so the operator may not be the one who pays. Cantons, foundations, associations that preserve small cableways and insurers all have an interest in safe ropes. During the pilot we will ask them whether they would pay for inspections or support the purchase of a robot.
Revenue streams
Offer | For whom | Price
Inspection as a service. We come with the robot, the operator gets the findings with photos and positions | Small cableways with one or two ropes | CHF 400 per rope
Subscription. The robot stays with the operator, with web app, model updates and a replacement if it fails | Operators with several installations | CHF 1,800 per robot and year

Both prices are planning assumptions. We will set them after the pilot, when we know what an inspection costs an operator today in money and in hours. With these assumptions a subscription pays for a field robot of CHF 600 within four months. It leaves CHF 1,200 in the first year and CHF 1,800 in every year after, which has to pay for the SIM card, the server, support and development. The magnetic head would later be sold as an upgrade.
Key resources and partners
Our resources are the design of the robot, its electronics and software, the trained network and the team that built all three. A fourth resource grows with every run, because each inspection adds photos of real ropes that make the next network better.
We need three partners.
- An operator who lets us run Cableguard on a real rope for one season.
- A testing body that compares our findings with its magnetic test of the same rope. Without that comparison nobody should trust our numbers.
- A workshop or manufacturer that can machine the iron parts of the magnetic head.
We have talked to several people from the ropeway sector. We are in deep conversations and have been invited to the most used cableway in Switzerland, at the airport, where we will soon ask for a test.
Company and funding
Today Kirchenfeldrobotics is a registered association, which is enough for a pilot. A limited company (GmbH) needs CHF 20,000 of share capital plus about CHF 2,000 to 4,600 for advice, the notary and the commercial register [24]. We plan to found it when the first operator pays, and until then we finance the pilot with prize money, sponsors and foundations. Our first stop is the free consultation of be-advanced, the innovation agency of the Canton of Bern [25]. Later we want to apply for the Initial Coaching of Innosuisse, a voucher of up to CHF 10,000 for start-up coaching [26].

## 4.6 Next steps

The prototype works on our test rig. Five steps separate it from a robot that an operator can use (Figure 18).
1. Real numbers and better eyes. We count hits, misses and false alarms on a rope with prepared damage. Then we merge the twin classes of the two photo collections and retrain the network
4 Social impact and innovation | 18 / 19

Each step towards a company has a gate that Cableguard has to pass

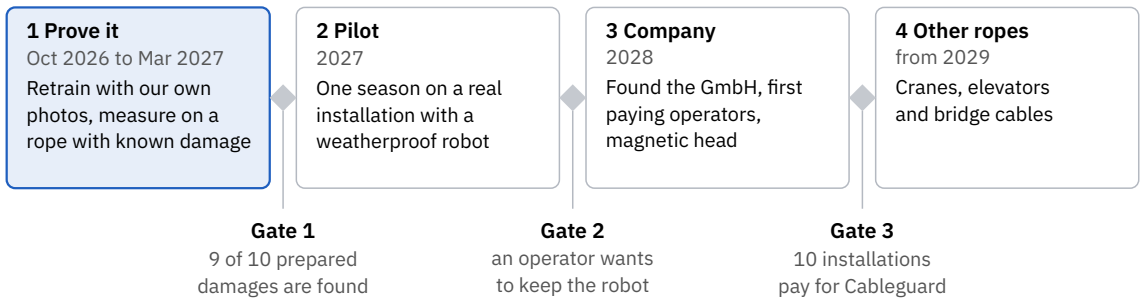
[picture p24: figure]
1 Prove it Oct 2026 to Mar 2027 Retrain with our own photos, measure on a rope with known damage; 2 Pilot 2027 One season on a real installation with a weatherproof robot; 3 Company 2028 Found the GmbH, first paying operators, magnetic head; 4 Other ropes from 2029 Cranes, elevators and bridge cables; Gate 1 9 of 10 prepared damages are found; Gate 2 an operator wants to keep the robot; Gate 3 10 installations pay for Cableguard

Figure 18. Our roadmap: four phases and three gates.
with photos from our own cameras. The photos the robot stores with every finding are the start of that collection.
2. More speed. At about 110 m per hour a long rope takes more than one night. The network sets the speed, so we will test a smaller network, an AI accelerator for the Raspberry Pi and a longer photo.
3. Ready for weather. A casing of ASA or aluminium with sealed openings, tested in rain and frost, and a catch that holds the robot if a wheel leaves the rope.
4. Inside the rope. We have the ring of Hall sensors and a software interface for a second sensor. Missing are the magnets in a yoke machined from iron, a safe way to put this head on the rope and a field model that turns the readings into findings. We want to solve this with a partner who has the machines.
5. A report an inspector can file. Each run should end in a PDF with every finding, its photo and position, a rating of its severity and a clear statement of what was not inspected.
For the first gate we need no partner, only a rope with prepared damage on our rig. For the second we need one operator and one rope, ideally a historic line like Fell–Spis in Nidwalden, which has run since 1932 [4]. Small cableways like this reach about 20 % of the Alps, and every second one has financial problems [4], so a cheap and frequent rope check can decide whether a line stays open. That is what we mean by guarding the lifelines of the Alps.
4 Social impact and innovation | 19 / 19

# Sources

Team and problem
1. https://kirchenfeldrobotics.ch
2. https://efk.admin.ch/wp-content/uploads/publikationen/berichte/sicherheit_und_umwelt/verkehr_und_umwelt/23767/23767be-wik-d.pdf (https://efk.admin.ch/wp-content/uploads/publikationen/berichte/sicherheit_und_umwelt/verkehr_und_umwelt/23767/23767be-wik-d.pdf)
3. https://en.wikipedia.org/wiki/Schweizer_Seilbahninventar and https://www.seilbahninventar.ch
4. https://www.srf.ch/radio-srf-1/im-ueberlebenskampf-kleinseilbahnen-kulturgut-in-luftiger-schieflage
5. https://www.ift.uni-stuttgart.de/institut/pdfs/Seilbahn-Broschuere-IFT.pdf
6. https://pmc.ncbi.nlm.nih.gov/articles/PMC5795951/
7. https://wro-association.org/wp-content/uploads/WRO-2026-Future-Innovators-Mission.pdf
Robotic solution
8. https://doi.org/10.3390/ma15207362
9. https://patents.google.com/patent/US8718352
10. https://inspenet.com/en/news/intelligent-robot-improves-bridge-inspection-with-machine-vision/
11. https://www.raspberrypi.com/products/raspberry-pi-5/
12. https://www.filamentive.com/outdoor-3d-printing-2025-uv-resistant-filament-uk-guide/
13. https://www.raspberrypi.com/news/piolib-a-userspace-library-for-pio-control/
14. https://docs.ultralytics.com/models/yolo26/
15. https://universe.roboflow.com/wirerope-qfgck/wire-rope-defect-f4qyg
16. https://universe.roboflow.com/yuan-9voxc/wire-rope-defect-review
Social impact and start-up
17. https://www.beobachter.ch/gesellschaft/kleinseilbahnen-nicht-sicher-vielen-seilbahnli-droht-das-aus
18. https://sdgs.un.org/goals/goal11
19. https://en.wikipedia.org/wiki/2025_Ascensor_da_Gl%C3%B3ria_derailment
20. https://en.wikipedia.org/wiki/Ascensor_da_Gl%C3%B3ria
21. https://en.wikipedia.org/wiki/Stresa%E2%80%93Mottarone_cable_car_crash
22. https://en.wikipedia.org/wiki/Doppelmayr/Garaventa_Group
23. https://www.credenceresearch.com/report/cable-car-and-ropeways-market
24. https://www.kmu.admin.ch/de/gmbh-haftung-stammkapital-gruendung
25. https://www.berninvest.be.ch/en/start/dienstleistungen/coaching-angebot.html
26. https://www.innosuisse.admin.ch/en/initial-coaching-for-start-up
Further sources
Sources 27 to 36 were opened on 3 October 2026.
27. https://oitaf.org/wp-content/uploads/2023/12/501814_Referat_Winter_-_Kuehner_-_Pernot.pdf
28. EN 12927:2019, Safety requirements for cableway installations designed to carry persons, Ropes (CEN)
29. https://www.swissinfo.ch/ita/italia-mottarone-perizia-68-fune-gi%C3%A0-rotta-prima-tragedia/47908270 (https://www.swissinfo.ch/ita/italia-mottarone-perizia-68-fune-gi%C3%A0-rotta-prima-tragedia/47908270)
30. https://econews.pt/?p=45601
31. https://www.zh.ch/de/mobilitaet/transportbewilligungen/personentransporte/bewilligung-kleinseilbahnen-skilifte.html (https://www.zh.ch/de/mobilitaet/transportbewilligungen/personentransporte/bewilligung-kleinseilbahnen-skilifte.html)
32. https://www.ultralytics.com/license
33. https://www.srf.ch/news/schweiz/neue-spitzenwerte-permafrost-taut-immer-weiter-auf
34. https://www.bav.admin.ch/dam/de/sd-web/rtTulUXa8A3o/leitfaden_permafrost.pdf
35. https://www.srf.ch/news/schweiz/unglueck-vor-50-jahren-bettmeralp-das-sind-die-lehren-aus-der-seilbahn-katastrophe (https://www.srf.ch/news/schweiz/unglueck-vor-50-jahren-bettmeralp-das-sind-die-lehren-aus-der-seilbahn-katastrophe)
36. https://www.wko.at/oe/transport-verkehr/seilbahnen/richtlinie-aenderung-intervall-augenscheinuntersuchung.pdf (https://www.wko.at/oe/transport-verkehr/seilbahnen/richtlinie-aenderung-intervall-augenscheinuntersuchung.pdf)
Sources | i

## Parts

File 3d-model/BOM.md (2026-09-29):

# Bill of Materials

## Custom parts

| Part | Qty | Material | File | Notes |
|---|---|---|---|---|
| Hub | 2 | PETG | print/stl/Hub.stl | drive wheel |
| Silicone Inlet | 2 | Silicone (cast) | print/stl/Silicone_Inlet.stl | traction insert |
| Drive Wheel Axis | 2 | Steel | cad/step/parts/Drive_Wheel_Axis.step | 16 mm |
| Spacer | 3 | Steel | cad/step/parts/Spacer.step | |
| Drum Shell Left | 1 | PETG | print/stl/Drum_Shell_Left.stl | |
| Drum Shell Right | 1 | PETG | print/stl/Drum_Shell_Right.stl | |
| Rotating Ring | 1 | PETG | print/stl/Rotating_Ring.stl | ring gear |
| Camera Lid | 1 | PETG | print/stl/Camera_Lid.stl | |
| Drum Drive Gear | 1 | PETG | print/stl/Drum_Drive_Gear.stl | |
| Drum Drive Gear Axis | 1 | Steel | cad/step/parts/Drum_Drive_Gear_Axis.step | 16 mm |
| Front Half Casing (Small) | 1 | PETG | print/stl/Front_Half_Casing_Small.stl | |
| Back Half Casing (Big) | 1 | PETG | print/stl/Back_Half_Casing_Big.stl | |
| Sliding Panel Front | 1 | PETG | print/stl/Sliding_Panel_Front.stl | |
| Sliding Panel Back | 1 | PETG | print/stl/Sliding_Panel_Back.stl | |
| Hinged Access Panel | 1 | PETG | print/stl/Hinged_Access_Panel.stl | |
| Mounting Block | 1 | PETG | print/stl/Mounting_Block.stl | |
| Button PCB Mount | 1 | PETG | print/stl/Button_PCB_Mount.stl | |
| Slide in Driver Mount | 1 | PETG | print/stl/Slide_in_Driver_Mount.stl | |
| Drive Belt Tensioner | 1 | PETG | print/stl/Drive_Belt_Tensioner.stl | |
| Button PCB | 1 | FR4 | cad/step/parts/Button_PCB.step | |

## Purchased parts

| Part | Qty | Link |
|---|---|---|
| NEMA 23 stepper AM23HS2449-01 | 2 | TODO |
| TB6600 stepper driver | 2 | TODO |
| Raspberry Pi 5 | 1 | TODO |
| Display | 1 | TODO |
| TOF200C distance sensor | 1 | TODO |
| Tactile button 12x12 mm | 3 | TODO |
| Cameras + LEDs | 2 | TODO |
| LTE / SIM module | 1 | TODO |
| 3S LiPo battery | 1 | TODO |
| GT2 belts + pulleys | 2 | TODO |
| Screws / heat-set inserts | - | TODO |

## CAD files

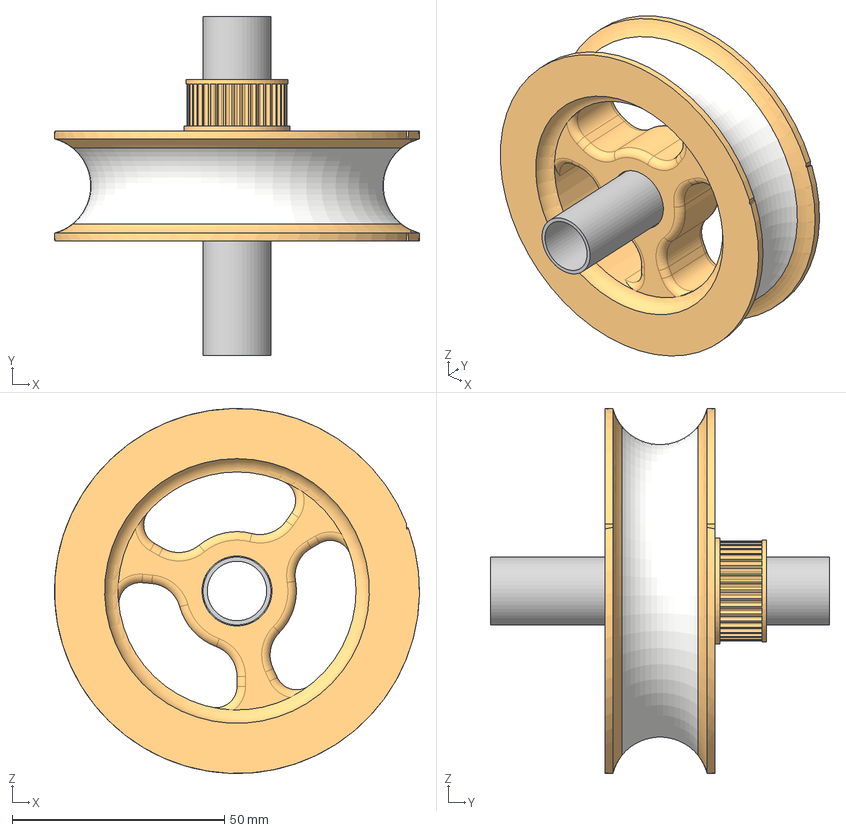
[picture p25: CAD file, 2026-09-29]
3d-model/cad/step/assemblies/Drive_Wheel.step
86.0 x 80.0 x 86.0 mm
Hub
Silicone Inlet
Drive Wheel Axis

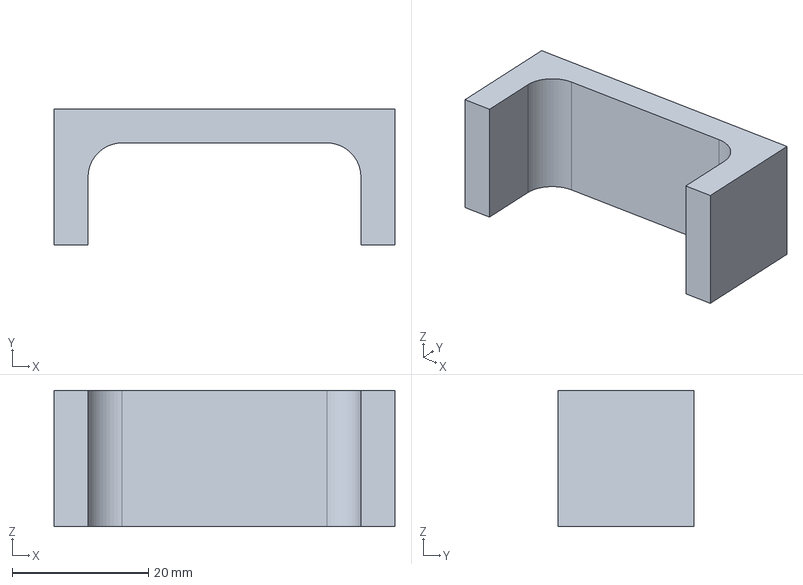
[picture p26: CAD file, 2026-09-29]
3d-model/cad/step/parts/Drive_Belt_Tensioner.step
50.0 x 20.0 x 20.0 mm

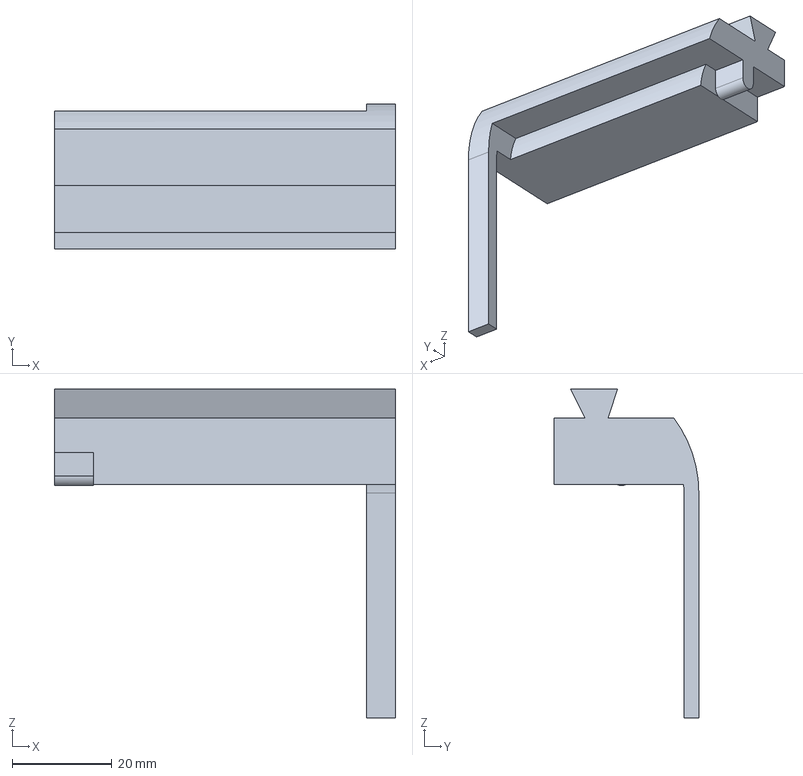
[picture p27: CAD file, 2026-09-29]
3d-model/cad/step/parts/Slide_in_Driver_Mount.step
68.3 x 29.0 x 65.8 mm

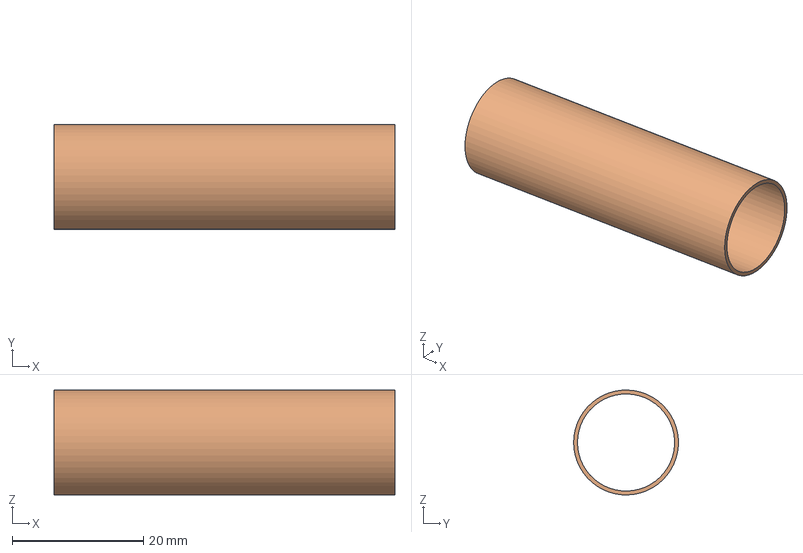
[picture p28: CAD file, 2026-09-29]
3d-model/cad/step/parts/Drum_Drive_Gear_Axis.step
52.0 x 16.0 x 16.0 mm

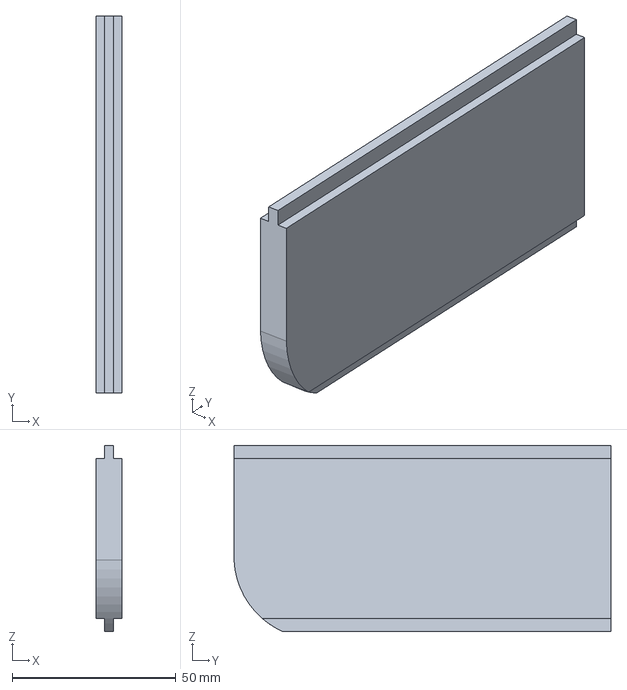
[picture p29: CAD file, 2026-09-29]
3d-model/cad/step/parts/Sliding_Panel_Back.step
7.80 x 115.0 x 56.8 mm

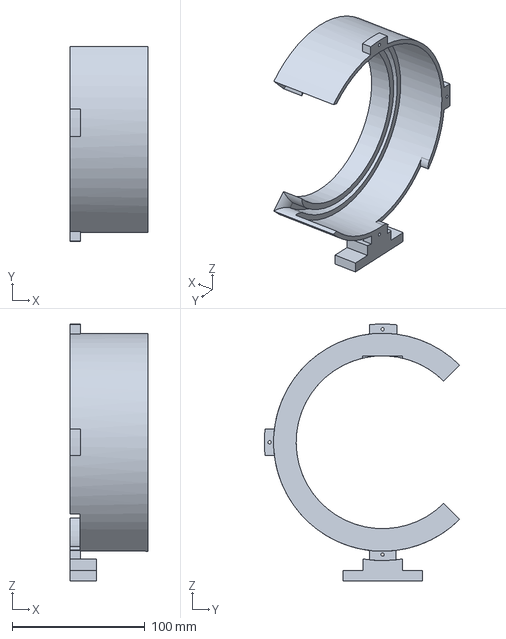
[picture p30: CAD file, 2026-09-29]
3d-model/cad/step/parts/Drum_Shell_Left.step
58.5 x 146.9 x 193.3 mm

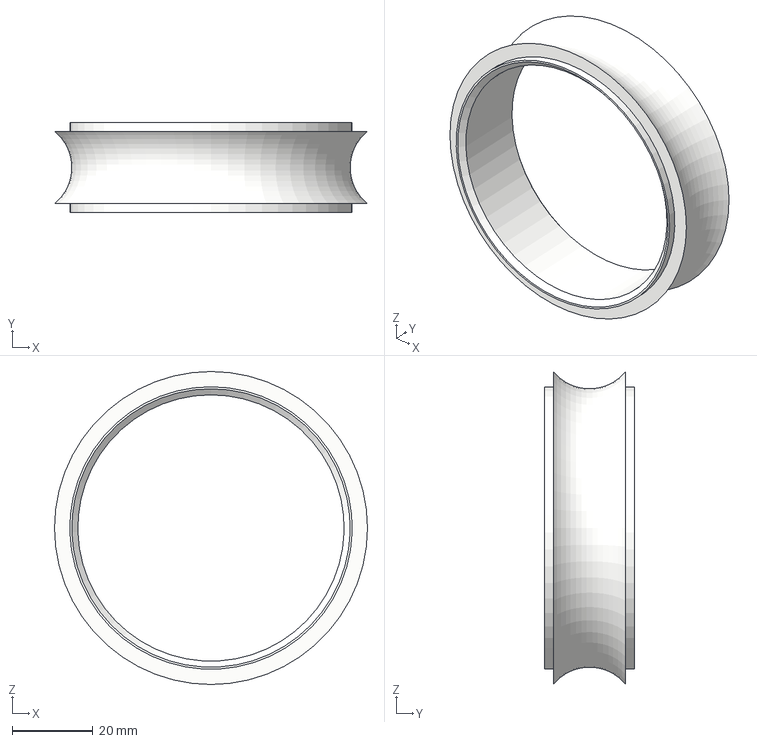
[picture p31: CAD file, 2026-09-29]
3d-model/cad/step/parts/Silicone_Inlet.step
77.6 x 22.4 x 77.6 mm

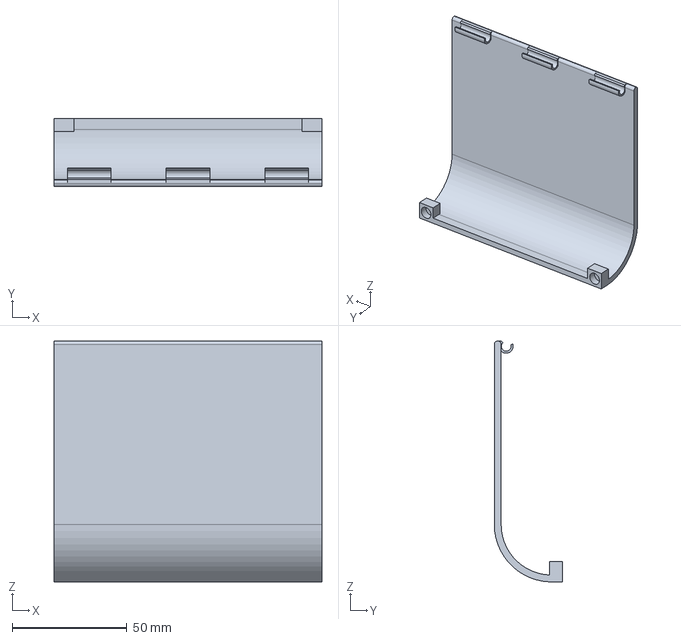
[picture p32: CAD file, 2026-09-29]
3d-model/cad/step/parts/Hinged_Access_Panel.step
116.6 x 29.8 x 104.8 mm

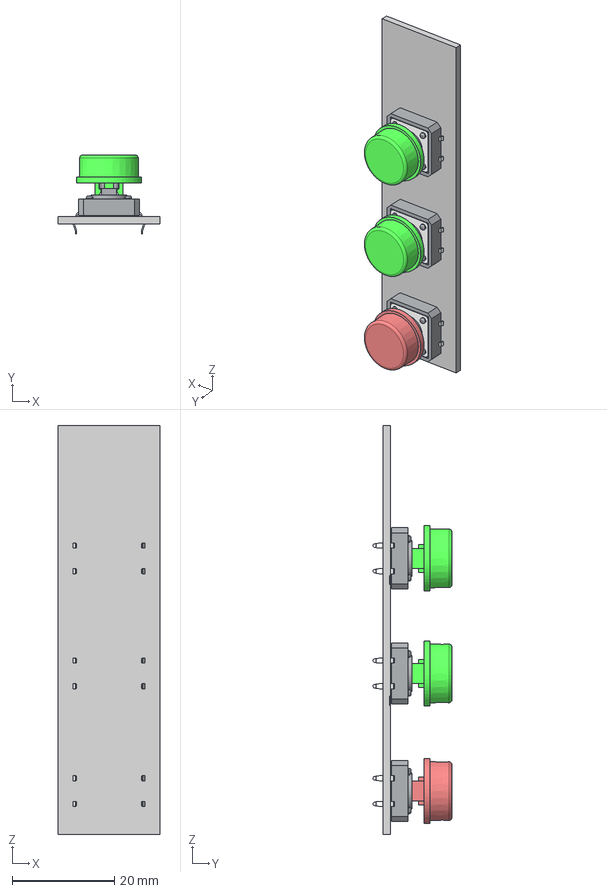
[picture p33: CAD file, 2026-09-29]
3d-model/cad/step/parts/Button_PCB.step
20.0 x 15.5 x 80.0 mm
base
plaque
appui
pin001 x 4
Capuchon
base_1 x 2
plaque_1 x 2
appui_1 x 2
pin001_1 x 8
Capuchon_1 x 2

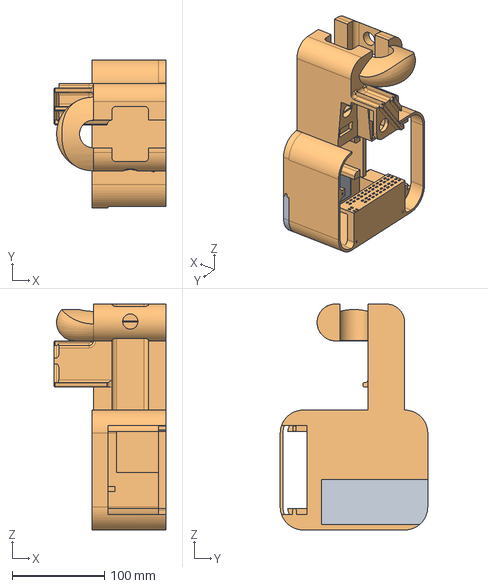
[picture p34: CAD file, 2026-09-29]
3d-model/cad/step/parts/Front_Half_Casing_Small.step
121.0 x 160.0 x 245.0 mm

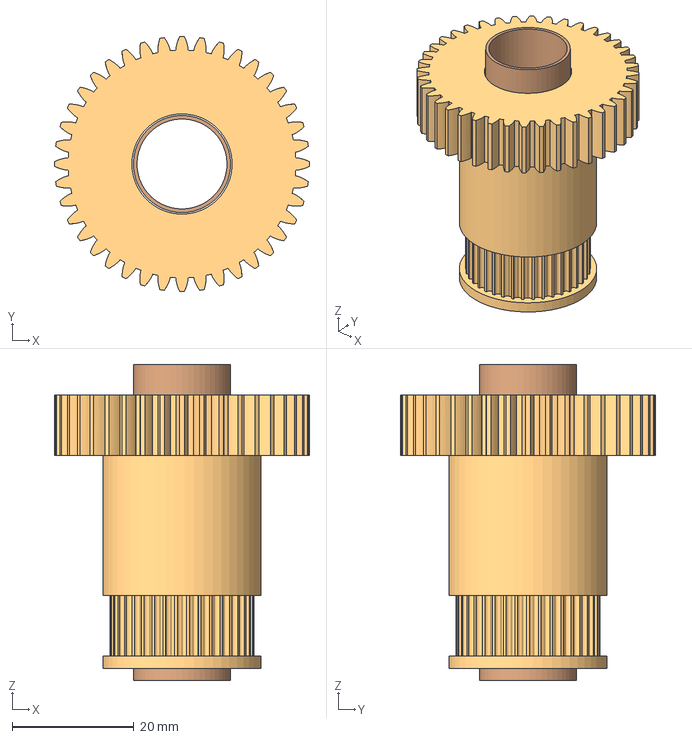
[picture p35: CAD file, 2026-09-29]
3d-model/cad/step/parts/Drum_Drive_Gear.step
42.0 x 42.0 x 52.0 mm

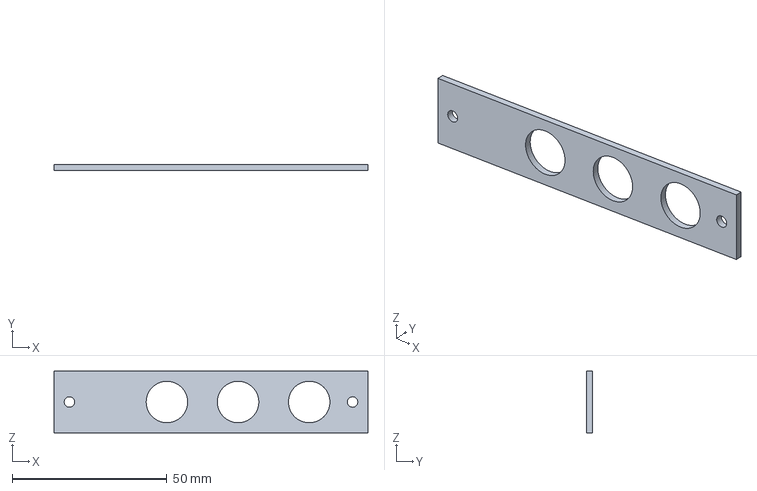
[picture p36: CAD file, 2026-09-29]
3d-model/cad/step/parts/Button_PCB_Mount.step
101.5 x 2.00 x 20.0 mm

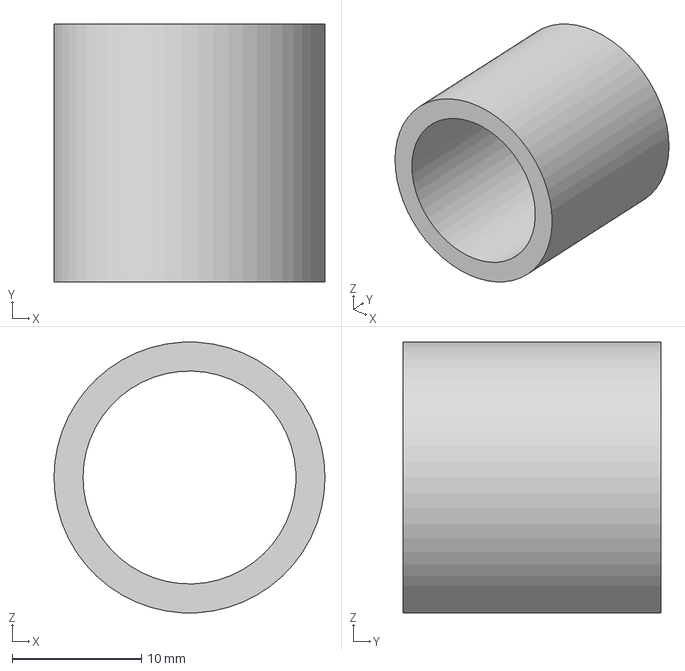
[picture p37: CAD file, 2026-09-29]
3d-model/cad/step/parts/Spacer.step
21.0 x 20.0 x 21.0 mm

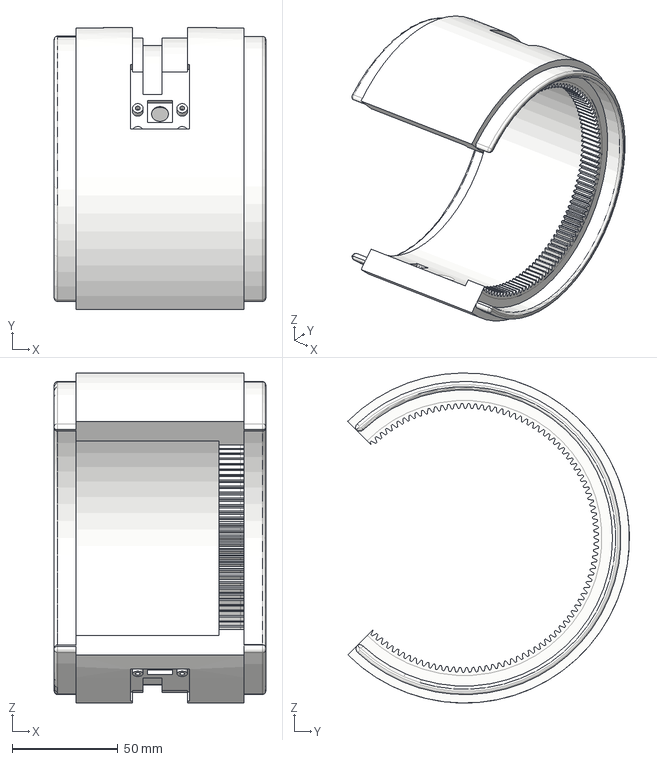
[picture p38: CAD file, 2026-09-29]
3d-model/cad/step/parts/Rotating_Ring.step
100.0 x 133.1 x 156.0 mm

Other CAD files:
3d-model/cad/step/parts/Back_Half_Casing_Big.step
3d-model/cad/step/parts/Drum_Shell_Right.step
3d-model/cad/step/parts/Sliding_Panel_Front.step
3d-model/cad/step/parts/Mounting_Block.step
3d-model/cad/step/parts/Camera_Lid.step
3d-model/cad/step/parts/Drive_Wheel_Axis.step
3d-model/cad/step/parts/Hub.step
3d-model/print/stl/Back_Half_Casing_Big.stl
3d-model/print/stl/Button_PCB_Mount.stl
3d-model/print/stl/Camera_Lid.stl
3d-model/print/stl/Drive_Belt_Tensioner.stl
3d-model/print/stl/Drum_Drive_Gear.stl
3d-model/print/stl/Drum_Shell_Left.stl
3d-model/print/stl/Drum_Shell_Right.stl
3d-model/print/stl/Front_Half_Casing_Small.stl
3d-model/print/stl/Hinged_Access_Panel.stl
3d-model/print/stl/Hub.stl
3d-model/print/stl/Mounting_Block.stl
3d-model/print/stl/Rotating_Ring.stl
3d-model/print/stl/Silicone_Inlet.stl
3d-model/print/stl/Slide_in_Driver_Mount.stl
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

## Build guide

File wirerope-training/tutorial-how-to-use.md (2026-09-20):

## Datasets

- https://universe.roboflow.com/wirerope-qfgck/wire-rope-defect-f4qyg
- https://universe.roboflow.com/yuan-9voxc/wire-rope-defect-review

Use Fork Dataset

## Setup

```bash
pip install -r requirements.txt
cp .env.example .env      # then put your Roboflow API key into it
```

Key into .env

## Run

1. Open `yolo26_wirerope_training.ipynb` and run the two download cells, they
   write to `datasets/A` and `datasets/B`.
2. Merge both exports into one dataset:
   ```bash
   python prepare_wirerope.py --src datasets/A datasets/B --out datasets/wirerope_merged
   ```
   The `--out` path is the `DATA` value in the notebook.
3. Run the rest of the notebook: training, validation, ONNX export, plots.

`datasets/`, `runs/`, `*.pt` and `*.onnx` are gitignored. The images are
several GB and GitHub blocks files over 100 MB.

Before pushing: `jupyter nbconvert --clear-output --inplace *.ipynb`, otherwise
the plot images end up base64-encoded in the diff.

## Export for the robot

```bash
python export_for_robot.py --weights weights/best.pt
```

Writes `robot/models/best_ncnn_model/` (param + bin + metadata.yaml), `best.onnx`
as fallback and `model.yaml` with version, imgsz and class names. The ncnn
folder is the only thing the robot needs, `robot/src/vision/detector.py` loads
it from there.

Keep `weights/best.pt`, it is the only thing that can be re-exported from.
`last.pt` is just the final epoch, needed only to resume an interrupted run.

## Deploy to the Pi

`robot/models/` is gitignored, so the weights do not travel with `git pull`.
The code goes over git, the model goes over ssh:

```bash
./scripts/deploy-model.sh pi@cableguard.local
```

Only needed after a new export, not after every code change.

## Testing on a laptop

```bash
python -m venv .venv                      # in the repo root
.venv/Scripts/python.exe -m pip install ultralytics ncnn pyyaml
```

```bash
.venv/Scripts/python.exe robot/src/vision/detector.py              # load + warmup only
.venv/Scripts/python.exe robot/src/vision/detector.py rope.jpg     # one or more images
.venv/Scripts/python.exe robot/src/vision/detector.py cam          # live webcam preview
```

The same ncnn folder runs on the laptop, no separate build needed.

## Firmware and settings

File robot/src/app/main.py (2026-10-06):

from __future__ import annotations

import asyncio
import itertools
import logging
import signal
import time
from dataclasses import dataclass

from comm_protocols.messages import (
    CloseCmd,
    DistanceTelemetry,
    MotionTelemetry,
    OpenCmd,
    ResetOriginCmd,
    SettingsCmd,
    SocketWatchCmd,
    StartCmd,
    StopCmd,
    UpdateCmd,
)
from comm_protocols.settings import RobotSettings

from app.buttons import Button
from app.buzzer import Buzzer, Sound
from app.ropesocket import RopeSocket
from app.runtime import Runtime
from app.update import Updater, software_version
from camera.camera import CameraPair, encode
from display.screen import Status, StatusScreen
from link.client import RobotLink
from link.outbox import Outbox
from link.video import VideoLink
from motion.controller import MotionController
from motion.drive import Drive
from motion.turret import Turret
from tof.vl53l0x import VL53L0X
from vision.detector import DetectorProcess
from vision.pacing import measure_cycle
from vision.report import vision_telemetry

log = logging.getLogger("cableguard")

# How the robot is wired. Everything else the robot runs on is a setting the operator owns
# from the webapp, see comm_protocols/settings.py: this is what a screwdriver changes, not
# a browser, and the software cannot tell whether a pin was rewired anyway

# the stepper that moves the robot along the rope
DRIVE_PUL_PIN = 18
DRIVE_DIR_PIN = 23

# the stepper that swings both cameras around the rope
TURRET_PUL_PIN = 12
TURRET_DIR_PIN = 16

# the two buttons on the robot, each wired from its pin to ground. Both pins are pulled up
# by the pi at boot, so a button held before the software claims it cannot start anything
START_BUTTON_PIN = 5        # red
STOP_BUTTON_PIN  = 6        # white

# the buzzer, wired from its pin to ground. It sits away from the two stepper pulse pins so
# that its own switching has nothing fast to couple into
BUZZER_PIN = 26

# distance sensor, a TOF200C (VL53L0X) on I2C bus 1 (SDA GPIO2, SCL GPIO3)
TOF_I2C_BUS = 1

# status display, a 0.96" 128x64 SSD1306 OLED. It shares I2C bus 1 with the distance sensor
DISPLAY_I2C_BUS = 1
DISPLAY_ADDRESS = 0x3C      # 0x3D on boards where the address pad is bridged
DISPLAY_FLIP = False        # True if the panel is mounted upside down

# the frame a defect was found in travels as a JPEG, the live stream at a lower quality
STREAM_JPEG_QUALITY = 95


# creates function that turns messages into roboter commands
def make_command_handler(rt: Runtime, motion: MotionController, buzzer: Buzzer,
                         updater: Updater):
    def handle(cmd):
        if isinstance(cmd, StopCmd):
            log.info("stop requested")
            buzzer.play(Sound.STOP)
            motion.emergency_stop()

        elif isinstance(cmd, StartCmd):
            # the update restarts this program any moment now, and a scan it cuts off has
            # lost the position it was measured from
            if updater.running:
                log.warning("start refused, the robot is updating")
                return

            # The speed is not ours to choose, the scan plan fixed it so that the detector
            # sees every bit of rope once. The round trip through metres is not bit exact,
            # and ramp_to reads anything below start_speed as a stop, so a plan sitting on
            # the drive's lower limit must not fall through it
            scan_speed = max(motion.drive.to_microsteps(rt.plan.speed_mps), motion.drive.start_speed)
            target = scan_speed if cmd.direction == "forward" else -scan_speed
            log.info("start requested: %s at %.3f m/s (%.0f microsteps/s)",
                     cmd.direction, rt.plan.speed_mps, scan_speed)
            buzzer.play(Sound.START)
            motion.request("speed", target)

        elif isinstance(cmd, ResetOriginCmd):
            if motion.drive.moving:
                log.warning("origin reset while moving, the run starts from here anyway")
            log.info("origin reset at %.2f m", motion.drive.metres_done)
            motion.drive.reset_steps_done()
            # the clear distance is measured from a position that just became zero
            rt.rope_socket.rebase(motion.drive.metres_done)

        elif isinstance(cmd, OpenCmd):
            rt.rope_socket.open_by_user()

        elif isinstance(cmd, CloseCmd):
            rt.rope_socket.close_by_user()

        elif isinstance(cmd, SocketWatchCmd):
            rt.rope_socket.set_watch(cmd.enabled)

        elif isinstance(cmd, SettingsCmd):
            # queued here, put in force by the detection cycle once the robot rests
            rt.accept(cmd.version, cmd.settings)

        elif isinstance(cmd, UpdateCmd):
            updater.request()

    return handle

# The buttons stand for the two commands the webapp sends most, so they are handed the same
# messages and run through the handler above: whatever a start comes to mean, the button
# follows. lgpio reports the press on its own thread, the command runs on the event loop
def make_button_press(loop, handle):
    def press(cmd):
        log.info("%s button pressed", cmd.type)
        loop.call_soon_threadsafe(handle, cmd)

    return press

# capture frames (streaming res.), encode, hand them to the video link
async def frame_producer(rt: Runtime, video: VideoLink):
    loop = asyncio.get_running_loop()

    while True:
        deadline = loop.time() + 1.0 / rt.settings.stream_fps
        try:
            for idx, lores in await asyncio.to_thread(rt.cams.capture_lores):
                video.submit(idx, encode(lores, STREAM_JPEG_QUALITY))
        except Exception:
            log.exception("capture failed")
        await asyncio.sleep(max(0.0, deadline - loop.time()))

# how the detector is keeping up, for the status display
@dataclass
class DetectionStats:
    cycle_ms: float | None = None     # how long the last detector cycle took

# Turn the cameras and report if the ring does not make it. A jammed ring costs the two
# sides it was meant to show, not the run, so the scan carries on either way
async def turn_cameras(turret: Turret, degrees: float, seconds: float | None = None) -> bool:
    try:
        await asyncio.to_thread(turret.turn_to, degrees, seconds)
        return True
    except Exception:
        log.exception("camera ring did not reach %.0f deg, it stands at %.0f deg", degrees, turret.angle)
        return False

# what one look at the rope produced, before the detector has seen any of it
@dataclass(frozen=True)
class Round:
    frames: list            # (camera index, image) for every camera
    captured_at: float      # epoch seconds
    microsteps: int         # where the drive stood when the shutter went
    metres: float


# One look at the rope: a frame from every camera. This is the only part of a round that
# needs the ring standing still
async def capture_round(rt: Runtime) -> Round:
    frames = await asyncio.to_thread(rt.cams.capture)
    # every frame of a round is from the same moment, taking the position per camera would
    # charge cam1 with the inference time of cam0
    return Round(frames, time.time(), rt.drive.microsteps_done, rt.drive.metres_done)


# The detector on what a round saw, and a report for every frame, empty ones included. It
# runs while the ring is already turning: the shutter needs the cameras still, the net does not
async def report_round(rt: Runtime, link: RobotLink, look: Round, seq):
    loop = asyncio.get_running_loop()
    quality = rt.settings.defect_jpeg_quality

    for idx, frame in look.frames:
        started = loop.time()
        found = await asyncio.to_thread(rt.detector.detect, frame)
        # only a frame with something in it is worth storing
        jpeg = await asyncio.to_thread(encode, frame, quality) if found else None
        millis = (loop.time() - started) * 1000.0

        if found:
            summary = ", ".join(
                f"{det.label} {det.confidence:.2f} at ({det.center[0]:.0f}, {det.center[1]:.0f})"
                for det in found
            )
            log.info("cam%d: %d detection(s) in %.0f ms: %s", idx, len(found), millis, summary)
        else:
            log.info("cam%d: nothing detected (%.0f ms)", idx, millis)

        msg = vision_telemetry(
            seq=next(seq),
            cam=idx,
            frame=frame,
            found=found,
            captured_at=look.captured_at,
            microsteps=look.microsteps,
            distance_from_origin=look.metres,
            inference_ms=millis,
            jpeg=jpeg,
        )
        # queued, not sent live: a detection that is not stored is a defect lost
        link.send(msg.model_dump())

# Walk the rope one cycle at a time: look, and turn the cameras a quarter turn while the
# detector works on what was just seen; look again from there, and turn back the same way.
# The drive holds a speed that covers exactly one frame of rope per cycle. While the robot is
# open for a rope socket the ring waits at the angle that clears it and the detector is idle;
# the cycle picks up again where it left off once the robot closes
async def detection_reporter(rt: Runtime, link: RobotLink, stats: DetectionStats,
                             buzzer: Buzzer):
    loop = asyncio.get_running_loop()
    seq = itertools.count(1)
    was_open = rt.rope_socket.is_open

    while True:
        # New settings wait for the robot to rest, and this loop is where it does. Between
        # cycles, drive stopped and ring parked, is the one moment at which the numbers all
        # of the below reads may be swapped out from under it
        rt.flush()
        plan = rt.plan
        open_angle = rt.open_angle

        # the sensor opens the robot on its own, so the sound follows the state and not the
        # command that may never have come
        if rt.rope_socket.is_open != was_open:
            was_open = rt.rope_socket.is_open
            buzzer.play(Sound.OPEN if was_open else Sound.CLOSE)

        # Open for a rope socket: the ring waits at the angle that clears it and no frame
        # goes through the detector. Driving and the video stream carry on
        if rt.rope_socket.is_open:
            # a turn that did not make it leaves the ring off its angle and is tried again,
            # at the pace of a cycle rather than of the poll
            reached = rt.turret.at(open_angle) or await turn_cameras(rt.turret, open_angle)
            rt.rope_socket.close_if_clear(rt.drive.metres_done)
            await asyncio.sleep(rt.settings.open_poll if reached else plan.period)
            continue

        # A standing robot sees the same bit of rope over and over, and inference keeps the
        # Pi hot. The ring rests open while it stands: that covers every way the robot can
        # come to a halt, a stop command as much as a lost link, and leaves it where the
        # next start takes it to be
        if not rt.drive.moving:
            if not rt.turret.at(open_angle):
                await turn_cameras(rt.turret, open_angle)
            await asyncio.sleep(plan.period)
            continue

        # scanning again, so the ring goes to where a cycle starts
        angles = rt.angles
        if not rt.turret.at(angles[0]):
            await turn_cameras(rt.turret, angles[0])

        deadline = loop.time() + plan.period
        try:
            # The ring already stands at the first angle. Every round is taken where it
            # stands and the ring then moves on to the next, the last one back to the first,
            # so the cycle ends where it began with no turn of its own
            for nxt in angles[1:] + angles[:1]:
                # a socket ahead ends the cycle here, no quarter turn is started into it
                if rt.rope_socket.is_open:
                    break
                look = await capture_round(rt)
                await asyncio.gather(
                    turn_cameras(rt.turret, nxt, plan.turn_s),
                    report_round(rt, link, look, seq),
                )
        except Exception:
            log.exception("detection failed")

        # the cycle was cut short for a rope socket: the ring is wanted at the angle that
        # clears it now, not after the rest of a cycle that is not being run
        if rt.rope_socket.is_open:
            continue

        slack = deadline - loop.time()
        stats.cycle_ms = (plan.period - slack) * 1000.0
        if slack < 0.0:
            log.warning("cycle overran its %.0f ms budget by %.0f ms, the rope is not fully covered",
                        plan.period * 1000.0, -slack * 1000.0)
        await asyncio.sleep(max(0.0, slack))

# stop robot when the control link is down
async def link_guard(rt: Runtime, link: RobotLink, motion: MotionController, buzzer: Buzzer):
    stopped = False       # a drive still ramping down is the same fault, not the next one
    while True:
        if not link.connected and rt.drive.moving:
            if not stopped:
                log.warning("control link down while moving => stopping")
                # nobody is watching the webapp for this one, it is the robot's own doing
                buzzer.play(Sound.FAULT)
                stopped = True
            motion.emergency_stop()
        else:
            stopped = False
        await asyncio.sleep(rt.settings.guard_period)

# send motion telemetry
async def telemetry_sender(rt: Runtime, link: RobotLink, updater: Updater, software: str | None):
    seq = 0
    while True:
        if link.connected:
            seq += 1
            try:
                msg = MotionTelemetry(
                    speed=rt.drive.speed,
                    speed_mps=rt.drive.speed_mps,
                    microsteps=rt.drive.microsteps_done,
                    metres=rt.drive.metres_done,
                    scan_speed_mps=rt.plan.speed_mps,
                    detect_fps=rt.plan.detect_fps,
                    robot_open=rt.rope_socket.is_open,
                    socket_watch=rt.rope_socket.watch,
                    socket_baseline_m=rt.rope_socket.baseline_m,
                    # the settings really in force, not the ones last received: that is what
                    # lets the webapp say whether a change has taken
                    settings_version=rt.version,
                    # an update is followed here as well: the script running, what it
                    # failed on, and after the restart the commit it left the robot on
                    software=software,
                    updating=updater.running,
                    update_error=updater.error,
                    seq=seq,
                )
                await link.send_live(msg.model_dump())
            except Exception:
                log.exception("telemetry failed")
        await asyncio.sleep(rt.settings.telemetry_period)

# The readings the sensor's normal is averaged from. They are taken back to back rather than
# at the rate the loop below polls: the sensor takes its own time over each one anyway, and
# nothing else happens until the robot knows what it is looking at
def sample_baseline(tof: VL53L0X, count: int) -> list:
    return [tof.read_m() for _ in range(count)]

# Read the distance sensor: it watches for the rope socket ahead and its reading is sent on
# as telemetry, live only. The sensor is opened here rather than at startup, so one that was
# not there yet or had a loose contact is picked up later. It is read whether or not the link
# is up, the robot opens for a socket on its own
async def distance_sender(rt: Runtime, link: RobotLink, bus: int):
    tof = None
    seq = 0
    failing = False
    try:
        while True:
            try:
                if tof is None:
                    tof = await asyncio.to_thread(VL53L0X, bus)
                    log.info("distance sensor ready")
                elif failing:
                    # a sensor that dropped out has lost its setup, it has to be set up again
                    await asyncio.to_thread(tof.reset)

                # What the sensor sees while the robot stands is the normal every later
                # reading is measured against, so it is taken at a standstill: a sensor that
                # only turned up mid run would otherwise take its normal from whatever the
                # robot is passing. An armed watch without a baseline is one still to be
                # calibrated, which is also how arming it again asks for another go
                if (rt.rope_socket.watch and rt.rope_socket.baseline_m is None
                        and not rt.drive.moving):
                    readings = await asyncio.to_thread(sample_baseline, tof,
                                                       rt.settings.socket_baseline_samples)
                    rt.rope_socket.calibrate(readings)

                distance = await asyncio.to_thread(tof.read_m)
            except (OSError, RuntimeError) as exc:
                # logged once, a loose wire would otherwise fill the journal twice a second
                if not failing:
                    log.warning("distance sensor not answering: %s", exc)
                failing = True
            else:
                if failing:
                    log.info("distance sensor answers again")
                failing = False
                rt.rope_socket.saw(distance, rt.drive.metres_done)

                if link.connected:
                    seq += 1
                    await link.send_live(DistanceTelemetry(distance_m=distance, seq=seq).model_dump())
            await asyncio.sleep(rt.settings.distance_period)
    finally:
        if tof is not None:
            tof.close()

# redraw the status display
async def display_updater(rt: Runtime, screen: StatusScreen, link: RobotLink, outbox: Outbox,
                          stats: DetectionStats):
    while True:
        status = Status(
            online=link.connected,
            backlog_bytes=outbox.backlog_bytes,
            speed_mps=rt.drive.speed_mps,
            metres=rt.drive.metres_done,
            cycle_ms=stats.cycle_ms,
        )
        try:
            await asyncio.to_thread(screen.show, status)
        except Exception:
            log.exception("display update failed")
        await asyncio.sleep(rt.settings.display_period)
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

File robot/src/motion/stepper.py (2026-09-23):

import lgpio, math, threading, time
from collections import deque

from motion import stepgen

# What every stepper on the robot has in common: a step pin fed by a PIO channel, a
# direction pin on plain GPIO, a ramp and an exact count of the steps that were played.
# The two drivers built on it are motion/drive.py, which moves the robot along the rope,
# and motion/turret.py, which swings the cameras around it
class Stepper():
    def __init__(self,
                 pul_pin,
                 dir_pin,
                 ena_pin=None,
                 chip=4,
                 dir_setup_s=0.001,
                 ena_settle_s=0.2,
                 invert_dir=False,
                 ena_active_high=False,
                 steps_per_rev=200,
                 microsteps=8,
                 ramp_segments=40,
                 start_speed=200.0,
                 max_speed=2000.0,
                 accel=400.0):

        # specify pin numbers
        self.pul_pin = pul_pin
        self.dir_pin = dir_pin
        self.ena_pin = ena_pin

        # specify driver timing, the pulse itself is fixed at 10 us by the PIO program
        self.dir_setup_s  = dir_setup_s   # break after direction high
        self.ena_settle_s = ena_settle_s  # break after enabled high

        # specify driver flags
        self.invert_dir      = invert_dir        # stepper direction inverted
        self.ena_active_high = ena_active_high   # stepper active on enabled high

        # specify steps
        self.full_steps_per_rev = steps_per_rev  # full steps per revolution
        self.microsteps         = microsteps     # microsteps per full step

        # how many constant-speed segments a ramp is approximated with
        self.n_ramp_segments = ramp_segments

        # speed
        self.start_speed = start_speed
        self.max_speed   = max_speed
        self.accel       = accel

        # the PIO takes the step pin over, lgpio must not claim it afterwards or the pin
        # falls back to plain GPIO
        self._channel = stepgen.open_channel(pul_pin)

        # lgpio (no daemon, unlike pigpio) drives direction and enable
        # chip 4 is the RP1 on the pi 5, chip 0 on older boards and newer kernels
        self.h = lgpio.gpiochip_open(chip)

        lgpio.gpio_claim_output(self.h, dir_pin, 0)

        if ena_pin is not None:
            lgpio.gpio_claim_output(self.h, ena_pin, 0)
            self.disable()

        # runtime vars
        self._speed   = 0.0
        self._forward = True
        self.abort    = threading.Event()   # cuts a running ramp short, see _emit

        # position: a block's steps are banked once the PIO reports it played, so the count
        # never runs ahead of the motor
        self._accum   = 0
        self._pending = deque()   # signed steps of every block the PIO has not played yet
        self._lock    = threading.Lock()

    def __enter__(self):
        self.enable()
        return self

    def __exit__(self, exc_type, exc, tb):
        self.close()

    # total amount of steps per revolution
    @property
    def steps_per_rev(self):
        return self.full_steps_per_rev * self.microsteps

    # returns moving state
    @property
    def moving(self):
        return self._speed > 0.0

    # return current speed
    @property
    def speed(self):
        return self._speed if self._forward else self._speed * -1

    # number of microsteps since last reset, signed with the direction driven
    @property
    def microsteps_done(self):
        return self._accum

    # number of steps since last reset
    @property
    def full_steps_done(self):
        return self.microsteps_done / self.microsteps

    # number of revolutions since last reset
    def revolutions_done(self):
        return self.full_steps_done / self.steps_per_rev

    # reset number of microsteps done
    def reset_steps_done(self):
        with self._lock:
            self._accum = 0

    # enable stepper (ena pin required)
    def enable(self):
        if self.ena_pin is None:
            return
        lgpio.gpio_write(self.h, self.ena_pin, 1 if self.ena_active_high else 0)
        time.sleep(self.ena_settle_s)

    # disable stepper (ena pin required)
    def disable(self):
        if self.ena_pin is None:
            return
        lgpio.gpio_write(self.h, self.ena_pin, 0 if self.ena_active_high else 1)

    # set spin direction of stepper
    def set_direction(self, forward):
        level = 1 if (forward != self.invert_dir) else 0
        lgpio.gpio_write(self.h, self.dir_pin, level)
        time.sleep(self.dir_setup_s)

    # ramp as a list of (speed, cycles) segments
    # the PIO takes a period plus a step count per block, not one entry per step,
    # so the ramp is approximated with n segments of constant speed
    def ramp_segments(self, v_from, v_to):
        v_from = max(v_from, self.start_speed)
        v_to   = max(v_to, self.start_speed)

        total = int(abs(v_to ** 2 - v_from ** 2) / (2. * self.accel))
        if total <= 0:
            return []

        n    = min(self.n_ramp_segments, total)
        per  = total // n
        done = 0

        segments = []
        for i in range(n):
            cycles = per if i < n - 1 else total - done
            mid    = done + cycles / 2.0   # speed taken at the middle of the segment

            if v_from < v_to:
                v = min(math.sqrt(v_from ** 2 + 2.0 * self.accel * mid), v_to)
            else:
                v = max(math.sqrt(max(v_from ** 2 - 2.0 * self.accel * mid, 0.0)), v_to)

            segments.append((v, cycles))
            done += cycles

        return segments

    # seconds a list of segments takes to play
    @staticmethod
    def duration(segments):
        return sum(cycles / v for v, cycles in segments)

    # bank the steps of every block the PIO has played since the last look, caller holds the lock
    def _reap(self):
        for _ in range(stepgen.done(self._channel)):
            self._accum += self._pending.popleft()

    # number of blocks the PIO has not played yet
    def _pending_blocks(self):
        with self._lock:
            self._reap()
            return len(self._pending)

    # hand one block to the PIO, False if its FIFO is full
    def _put(self, v, cycles):
        with self._lock:
            self._reap()
            if len(self._pending) >= stepgen.FIFO_DEPTH:
                return False
            if not stepgen.put(self._channel, int(round(1e6 / v)), cycles):
                raise ValueError(f"{cycles} steps at {v:.0f} microsteps/s do not fit in a PIO block")
            self._pending.append(cycles if self._forward else -cycles)
            return True

    # queue one block of pulses, blocks until there is room in the queue
    def _queue(self, v, cycles):
        while not self._put(v, cycles):
            time.sleep(0.001)
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

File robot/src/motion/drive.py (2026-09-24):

import threading
import time

from motion.stepper import Stepper

# Motor turns for one turn of the drive wheel. Placeholder until the drive is measured:
# 1.0 means the motor sits on the wheel axis, a reduction between the two makes it larger
GEAR_RATIO = 1.0

# How far the robot travels for one turn of the drive wheel. Placeholder until the drive is
# measured: the circumference of a 50 mm wheel
METRES_PER_REV = 0.15708


# The stepper that moves the robot along the rope. It runs at a speed the scan plan picks
# and holds it for as long as the operator lets it, so cruise is fed in finite blocks by a
# thread of its own: that keeps every step countable without stopping between blocks
class Drive(Stepper):
    def __init__(self,
                 pul_pin,
                 dir_pin,
                 gear_ratio=GEAR_RATIO,
                 metres_per_rev=METRES_PER_REV,
                 cruise_block_s=0.02,
                 cruise_blocks_ahead=3,
                 **kwargs):                 # the rest is the base driver's, see stepper.py

        super().__init__(pul_pin, dir_pin, **kwargs)

        # Drive geometry: what the motor turns, and how far that carries the robot. Both
        # are measured on their own, the microsteps and the metres only meet below
        self.gear_ratio     = gear_ratio
        self.metres_per_rev = metres_per_rev

        # One cruise block = one word to the PIO. Enough blocks stay queued to ride out a
        # busy CPU, few enough that a stop is not stuck behind them for long
        self.cruise_block_s      = cruise_block_s
        self.cruise_blocks_ahead = cruise_blocks_ahead

        self._cruise_speed = 0.0
        self._closing      = threading.Event()
        self._feeder       = threading.Thread(target=self._feeder_loop, daemon=True)
        self._feeder.start()

    # Take a new set of the operator's numbers. Only safe while the drive stands: all of
    # them are read inside a running ramp, and the geometry turns the microsteps already
    # counted into a different number of metres
    def configure(self, microsteps, gear_ratio, metres_per_rev, start_speed, max_speed, accel):
        self.microsteps     = microsteps
        self.gear_ratio     = gear_ratio
        self.metres_per_rev = metres_per_rev
        self.start_speed    = start_speed
        self.max_speed      = max_speed
        self.accel          = accel

    # Microsteps the motor makes for one metre along the rope: the whole drive train in one
    # number, and the only place microsteps and metres meet. Microstepping divides the motor
    # turn, the gearing divides it again, and one turn of the wheel is one metres_per_rev
    @property
    def microsteps_per_metre(self):
        return self.steps_per_rev * self.gear_ratio / self.metres_per_rev

    # metres for a microstep count. Speeds convert with the same factor, microsteps per
    # second over microsteps per metre is metres per second
    def to_metres(self, microsteps):
        return microsteps / self.microsteps_per_metre

    # microsteps for a distance in metres, or microsteps per second for a speed in m/s
    def to_microsteps(self, metres):
        return metres * self.microsteps_per_metre

    # distance since last reset, signed with the direction driven
    @property
    def metres_done(self):
        return self.to_metres(self.microsteps_done)

    # current speed in metres per second, signed like speed
    @property
    def speed_mps(self):
        return self.to_metres(self.speed)

    # tops up the queue while cruising, so cruise steps stay counted
    def _feeder_loop(self):
        while not self._closing.is_set():
            v = self._cruise_speed
            if v > 0.0 and self._pending_blocks() < self.cruise_blocks_ahead:
                self._put(v, max(1, int(self.cruise_block_s * v)))
            time.sleep(self.cruise_block_s / 4.0)

    # ramp to speed and cruise there (if cruise flag is set)
    def ramp_to(self, speed, cruise=True):
        target  = min(abs(speed), self.max_speed)
        forward = speed >= 0

        if self.moving and forward != self._forward:
            self.stop()

        if target < self.start_speed:
            self.stop()
            return

        if not self.moving:
            self.set_direction(forward)
            self._forward = forward

        completed = self._emit(self.ramp_segments(self._speed, target), abortable=True)

        if not completed:
            return

        if cruise:
            self._speed        = target
            self._cruise_speed = target   # hand over to the feeder thread
        else:
            self._wait_idle()
            self._speed = 0.0

    # stop feeding cruise blocks. Safe to call from any thread: the feeder picks it up on
    # its next pass and the queued blocks then play out within cruise_blocks_ahead blocks.
    # stop() has to run on the motion thread, this does not
    def cut_cruise(self):
        self._cruise_speed = 0.0

    # ramp stepper to 0.0
    def stop(self):
        if not self.moving:
            return

        self._cruise_speed = 0.0   # feeder stops adding blocks first

        segments = self.ramp_segments(self._speed, 0.0)
        if segments:
            self._emit(segments)

        # Blocks already handed to the PIO cannot be taken back, so the ramp and any cruise
        # block still queued play out first. Waiting for them keeps the position exact and
        # makes sure the last pulse is over before the direction may change
        self._wait_idle()
        self._speed = 0.0

    def close(self):
        try:
            self.stop()
        finally:
            self._closing.set()
            self._feeder.join(timeout=1.0)
            super().close()

    # keep script running for n seconds
    def hold_s(self, seconds):
        if seconds <= 0:
            return

        time.sleep(seconds)

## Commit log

2026-08-31 fixed database connection + added lifespan
    [main.py]
2026-09-01 added untested stepper driver
2026-09-09 added camera read to robot code (picamera2)
2026-09-09 Added video stream logic (fixed shared package bug)
    [camera.py, main.py]
2026-09-12 Implemented various bug fixes, added speed control to webaoo, motion telemetry, command confirmation, some other minor additons
    [camera.py, controller.py, main.py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]
2026-09-14 migrated stepper driver from pigpio to lgpio
2026-09-19 fix camera configuration for video stream
    [camera.py]
2026-09-19 ajusted camera configs (fixed encode function for RGB888)
    [camera.py]
2026-09-19 higher camera quality
2026-09-19 fixed webapp cmaera preview boarder, random grpahify idk please soon delete graphify
2026-09-20 fixed focus of camera on 5cm
    [camera.py]
2026-09-20 created logg of camera detection
2026-09-20 fixed camera focus
2026-09-20 fixed main.py for clean install of ultralytics
    [main.py]
2026-09-20 vision no longer an optional task
    [main.py]
2026-09-20 Removed unused buttons from webapp (Emergency stop and plan new session)
2026-09-20 fixed "no run selected issue" and "robot doesnt stop issue"
    [controller.py, stepper.py]
2026-09-21 stepper driver bug fix
    [stepper.py]
2026-09-21 Added frame to defect payload
2026-09-22 stepper driver migration to c wrapper
2026-09-22 Detector interference runs now in its own process (stalled the entier program before)
    [detector.py, main.py, pacing.py]
2026-09-22 TOF sensor implementation
2026-09-22 Implementation of stepper revoution (new concept + code)
2026-09-23 Added pillar event: If there is a rope socket or the user opens the robot, the turret moves to -20°
2026-09-23 Display migration (smaller display, i2c)
2026-09-23 Manual calibration system
2026-09-23 Made camera revolutions cycle more efficient.
2026-09-23 camera rotation stepper max speed constraint changed from s to deg/s
2026-09-23 Fixed dataflow issue in motion speed calculations
    [main.py, pacing.py]
2026-09-23 minor motion speed calculation fix. Changed headroom
    [main.py, pacing.py]
2026-09-24 added gear ratio to motion too
2026-09-26 added button and buzzer logic
    [buttons.py, buzzer.py, main.py]
2026-09-26 camera stepper fix + pin map
    [drive.py, main.py, ropesocket.py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]
2026-09-26 camera stepper fix
2026-09-26 rewind stepper fixes (hardware issue)
    [buzzer.py, drive.py, main.py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]
2026-09-28 tof sensor logic fix
    [main.py, ropesocket.py, runtime.py]
2026-09-29 added all 3D files
    [Back_Half_Casing_Big.step, Back_Half_Casing_Big.stl, Button_PCB.step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]
2026-10-01 renamed folder
    [Back_Half_Casing_Big.step, Back_Half_Casing_Big.stl, Button_PCB.step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]
2026-10-01 Rename 'Vcc' to 'VDD' in cable_label.md
2026-10-01 Rename SCL to SCK in cable_label.md
2026-10-01 Update cable_label.md with voltage considerations
    Added note regarding voltage levels for I^2C connections.
2026-10-01 Update pins.md with display pin information
    Added display pin connections to pins.md
2026-10-02 robot info, belt size
2026-10-10 added the rope-full-26n-v3 ncnn model
    [model.ncnn.param]
2026-10-11 added cpu temperature to webapp
2026-10-11 autofocus for cameras (removed manual focus)
2026-10-13 pin swap test
2026-10-13 camera stepper pin rewind
2026-10-13 button press causes two cmds issues fix
